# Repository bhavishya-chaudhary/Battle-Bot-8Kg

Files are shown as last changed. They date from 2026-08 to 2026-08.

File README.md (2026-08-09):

# Battle Bot — 8 kg Vertical Spinner

An 8 kg vertical spinner combat robot designed and built by **Team Spartans** for RoboWars. The robot combines a custom aluminium chassis, impact protection, chain-driven weapon system, differential drivetrain, and an ESP32-based control system.

The project was developed through prototype validation, final integration, testing, and competition.

## Specifications

| Parameter | Specification |
|---|---|
| Robot class | 8 kg |
| Configuration | Vertical spinner |
| Drive | Differential / tank steering |
| Drive motors | 24 V geared DC, ~468 RPM |
| Motor drivers | BTS7960 |
| Wheels | 100 mm |
| Weapon motor | D3548 BLDC, 790 KV |
| Weapon ESC | 80 A, 6S |
| Weapon transmission | Chain and sprocket |
| Controller | ESP32-WROOM |
| Radio | FlySky FS-i6S + FS-i10AB |
| Battery | 2 × 3S 4200 mAh 35C LiPo, series |
| Chassis | Aluminium |
| Side protection | 15 mm UHMWPE + stainless steel |
| Low-voltage supply | XL4051 5 A buck converter |
| Control | RC + ESP32 Web UI |
| Firmware | Custom ESP32 firmware with OTA |

## System Architecture

```mermaid
flowchart LR
    TX["FlySky FS-i6S<br/>Transmitter"]
    RX["FS-i10AB<br/>Receiver"]
    ESP["ESP32-WROOM<br/>Control & Safety"]

    DRIVE["BTS7960<br/>Motor Drivers"]
    DM["24 V<br/>Drive Motors"]

    ESC["80 A ESC"]
    WM["D3548<br/>790 KV BLDC"]

    TX --> RX --> ESP
    ESP --> DRIVE --> DM
    ESP --> ESC --> WM
```

The ESP32 acts as the control layer between the RC receiver and the actuators, providing signal processing, mixing, control shaping, weapon control, arming, failsafes, configuration, and diagnostics.

## Mechanical Design

The chassis was designed in **SolidWorks** and packaged around the drivetrain, weapon, battery, and electronics.

The final structure uses:

- Aluminium chassis plates
- 15 mm UHMWPE side protection
- Stainless-steel reinforcement
- Integrated mounts for the drivetrain and weapon
- 100 mm heavy-duty wheels

The weapon uses a vertical spinner driven by a **D3548 790 KV BLDC motor** through a chain and sprocket transmission.

The spinner CAD model has a calculated mass of **557.24 g**. This value refers to the spinner model itself and does not include the complete rotating assembly such as the shaft, sprocket, or motor.

## Drivetrain

The robot uses differential steering with independently controlled left and right drive systems.

Each side uses a 24 V geared DC motor rated at approximately:

- **468 RPM**
- **72.6 N·cm torque**

BTS7960 drivers control the drive motors.

The 100 mm drive wheels were fitted with cut cricket-bat grip rubber to improve traction.

## Control System

The ESP32 acts as the control layer between the RC receiver and the actuators.

The firmware handles:

- RC signal processing
- Differential/tank mixing
- Polynomial throttle and steering curves
- Weapon control
- Independent drive and weapon arming
- Radio-loss failsafe
- Watchdog and reset handling
- Web-based configuration and diagnostics
- OTA firmware updates

### Weapon Control

Weapon output can be selected through three transmitter modes:

| Mode | Output |
|---|---:|
| Controlled | ~50% |
| Higher Power | ~90% |
| Full Power | 100% |

The weapon potentiometer provides the normal control input, while the transmitter switch changes its available output range.

## Safety

The robot uses multiple independent safety mechanisms:

- Physical kill switch
- Radio-loss failsafe
- ESP32 watchdog
- Brownout/reset handling
- Emergency/failsafe command
- Independent drivetrain and weapon arming

The drivetrain and weapon can therefore be armed independently during testing and operation.

## Power & Electronics

The main power system uses **two 3S 4200 mAh 35C LiPo batteries in series**, providing a 6S supply:

- Nominal voltage: **22.2 V**
- Fully charged voltage: **25.2 V**
- Capacity: **4200 mAh**

The electrical system includes an 80 A weapon ESC, BTS7960 motor drivers, XL4051 buck converter, TVS protection, AWG 10 high-current wiring, XT60 connectors, and a 24 V cooling fan.

## Development

The robot was developed in stages rather than integrating the final combat system immediately.

```mermaid
flowchart LR
    A["CAD &<br/>System Design"]
    B["Simplified<br/>Prototype"]
    C["Electronics &<br/>Firmware Validation"]
    D["Final<br/>Integration"]
    E["RoboWars"]

    A --> B --> C --> D --> E
```

The prototype was used to validate the ESP32 control system, RC communication, motor control, weapon control, mixing, and safety logic before the final chassis was fabricated.

The prototype used a direct flexible weapon coupling, while the final robot used the chain-and-sprocket transmission.

## Competition & Failure

The completed robot competed at **RoboWars** and reached Round 2.

During combat, the **weapon transmission sprocket broke under loading**, stopping the weapon and contributing to the loss.

The failure exposed a limitation that was not apparent during normal testing: combat introduces transient shock loads significantly different from steady-state operation. It highlighted the need to consider impact loading and transmission component strength when designing combat mechanisms.

## My Contribution

This was a team project under **Team Spartans**. My work covered the mechanical design, electronics integration, embedded control, and system integration.

### Mechanical

- Designed the main chassis in SolidWorks
- Worked on internal packaging and component placement
- Designed the weapon mounting/support structure
- Worked on drivetrain and weapon transmission design

### Electronics & Control

- Designed and integrated the electronics architecture
- Developed the ESP32 control system
- Implemented mixing and polynomial control curves
- Implemented weapon control and power modes
- Implemented arming and failsafe logic
- Developed the Web UI and OTA functionality

### Integration

- Validated the prototype
- Integrated mechanical, electrical, and software systems
- Worked on final assembly and testing

## Project Status

**Completed — Competed at RoboWars**

The robot reached competition, with the weapon transmission sprocket failing during Round 2.

## License

This project is released under the [MIT License](LICENSE).

---

## Images

Unless otherwise stated, all photographs, renders, and project images in this repository are © Bhavishya Chaudhary.

The images are provided to document the development of the project and may not be reproduced, redistributed, or used in other projects without permission.

The source code in this repository remains licensed under the MIT License.

---

## Author

**Bhavishya Chaudhary**

If you have any questions or suggestions, feel free to connect with me on LinkedIn or GitHub.

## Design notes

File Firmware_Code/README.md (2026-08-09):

This directory contains CAD model related to this project.

Copyrights and Usage Restrictions:
Unless otherwise stated, all CAD models in this repository are © Bhavishya Chaudhary.

The CAD are provided to document the development of the project and may not be reproduced, redistributed, or used in other projects without permission, for permission you can contact me on LinkedIn www.linkedin.com/in/bhavishya-chaudhary-svnit .

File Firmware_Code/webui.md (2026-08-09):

# Web UI

## Access

-   **Wi-Fi SSID:** `update it in firmware before flashing it at line 45`
-   **Wi-Fi Password:** `update it in firmware before flashing it at line 46`
-   **Dashboard:** `http://<ESP32-IP>/`
-   **OTA Update:** `http://<ESP32-IP>/update`
-   **OTA Username:** `admin`
-   **OTA Password:** `ota_secret_99`
-   **Telnet:** `<ESP32-IP>:23`

## Dashboard

### Live Telemetry

-   14-channel iBUS monitor
-   Throttle raw / output
-   Steering raw / output
-   Left / right motor speed
-   Left / right forward / reverse PWM
-   Arm status
-   ESC status
-   Weapon lock status
-   Weapon limit
-   Target / current weapon PWM
-   Weapon output percentage
-   Ramping status
-   Failsafe status
-   RC signal age
-   Good / bad iBUS frames
-   Uptime
-   Wi-Fi RSSI
-   Free heap
-   ESP32 IP address
-   System status

### Drive Tuning

-   Left Forward trim
-   Left Reverse trim
-   Right Forward trim
-   Right Reverse trim
-   Maximum throttle
-   Maximum steering
-   Throttle curve
-   Steering curve
-   Throttle deadzone
-   Steering deadzone
-   Save All
-   Reset All
-   EEPROM persistence

### Serial Monitor

-   Live firmware log
-   Clear log

## OTA Update

-   Authenticated firmware upload
-   `.bin` firmware update
-   Automatic reboot after successful update

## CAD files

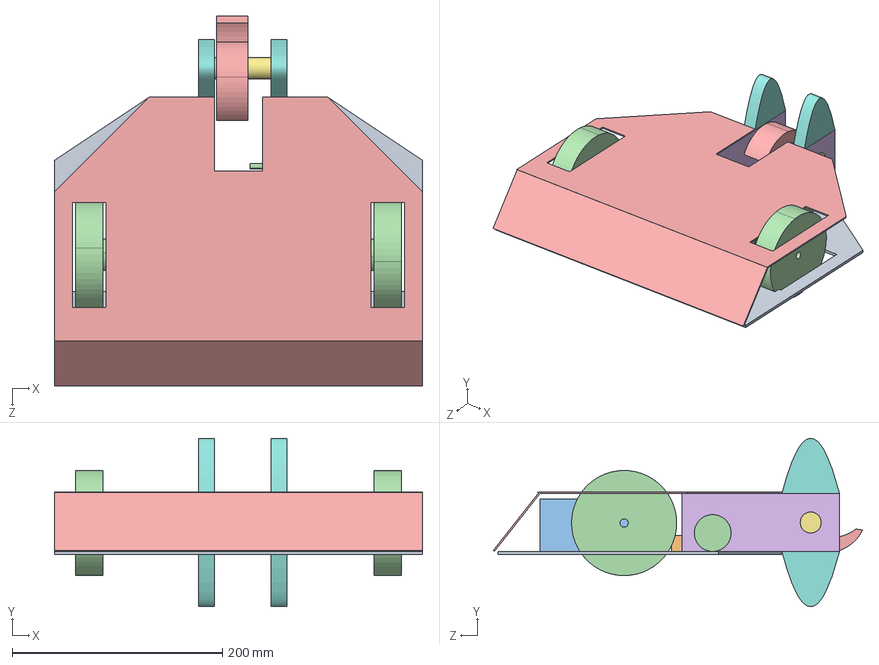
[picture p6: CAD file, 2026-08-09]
CAD/Main_Bot.STEP
350.0 x 160.0 x 351.5 mm
Base_plate
L_clamp x 2
Motor x 2
Wheel x 2
Top_Plate
Bearing_housing x 2
Shaft
Front_support x 4
Battery x 2
ESC
Motor_Driver x 2
BLDC_motor
Attacker_v5

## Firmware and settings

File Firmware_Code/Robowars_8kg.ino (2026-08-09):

/*
 * ================================================================
 *  BATTLE BOT CONTROLLER v7.2
 *  ESP32 WROOM -- NO EXTERNAL LIBRARIES FOR IBUS
 * ================================================================
 *
 *  v7.2 CHANGES:
 *    - ESC arm is hardware arming sequence only (3s 1000us at boot)
 *    - "Armed" on dashboard = CH5 arm lock (drive + weapon gate)
 *    - CH7 (3-pos) is weapon lock/limit:
 *        Pos1 = LOCKED (weapon always 1000us, no spin)
 *        Pos2 = UNLOCKED, limit 3/6 (50%)
 *        Pos3 = UNLOCKED, limit 5/6 (83%)
 *    - CH8 override still goes to 100% (bypasses limit, not lock)
 *    - CH8 override ONLY works when CH7 is Pos2 or Pos3 (unlocked)
 *    - ESC Armed display now shows ESC hardware arm status only
 *    - Weapon Lock display shows CH7 lock state
 *    - Poll 100ms, PollLog 250ms
 *
 *  WEAPON LOGIC:
 *    CH5 OFF  -> all stopped (drive + weapon)
 *    CH5 ON + CH7 Pos1 -> drive works, weapon LOCKED at 1000us
 *    CH5 ON + CH7 Pos2 -> drive + weapon at knob * 50%
 *    CH5 ON + CH7 Pos3 -> drive + weapon at knob * 83%
 *    CH5 ON + CH7 Pos2/3 + CH8 ON -> weapon 100% override
 *
 *  EEPROM LAYOUT (v7.1 compatible):
 *    Byte 0:     Magic (0xBC)
 *    Byte 1-16:  4x float trims
 *    Byte 17-32: maxT, maxS, curveT, curveS, deadT, deadS
 *
 * ================================================================
 */

#include <WiFi.h>
#include <WebServer.h>
#include <Update.h>
#include <EEPROM.h>
#include <esp_task_wdt.h>

// ================================================================
//  WIFI CREDENTIALS -- EDIT THESE
// ================================================================

const char* WIFI_SSID     = "enter your Wifi name here";
const char* WIFI_PASSWORD = "enter your Wifi password here";

// ================================================================
//  DEBUG
// ================================================================

#define DEBUG_MODE false
#define RAMP_TRACE true

// ================================================================
//  WEB OTA SETTINGS
// ================================================================

const char* OTA_USERNAME  = "admin";
const char* OTA_PASSWORD  = "ota_secret_99";

// ================================================================
//  WIFI SETTINGS
// ================================================================

const unsigned long WIFI_CONNECT_TIMEOUT_MS = 10000;
const unsigned long WIFI_ACTIVE_TIMEOUT_MS  = 120000;

#define TELNET_PORT 23

// ================================================================
//  PINS
// ================================================================

#define IBUS_RX_PIN     16

#define LEFT_RPWM_PIN   25
#define LEFT_LPWM_PIN   26
#define RIGHT_RPWM_PIN  27
#define RIGHT_LPWM_PIN  13

#define ESC_PIN         33

// ================================================================
//  LEDC CHANNELS
// ================================================================

#define LEDC_CH_L_FWD   0
#define LEDC_CH_L_REV   1
#define LEDC_CH_R_FWD   2
#define LEDC_CH_R_REV   3
#define LEDC_CH_ESC     4

// ================================================================
//  IBUS
// ================================================================

#define IBUS_CH_STEERING    0
#define IBUS_CH_THROTTLE    1
#define IBUS_CH_ARM         4
#define IBUS_CH_RAMP        5
#define IBUS_CH_LIMIT       6
#define IBUS_CH_OVERRIDE    7
#define IBUS_CH_KNOB        9

#define IBUS_CHANNELS       14
#define IBUS_LENGTH         32
#define IBUS_COMMAND        0x40

// ================================================================
//  PWM
// ================================================================

#define DRIVE_PWM_FREQ       20000
#define DRIVE_PWM_RES        8
#define ESC_PWM_FREQ         50
#define ESC_PWM_RES          16

// ================================================================
//  TIMING
// ================================================================

#define FAILSAFE_TIMEOUT_MS  250
#define ESC_ARM_TIME_MS      3000

#define RAMP_SLOW_STEP       10
#define RAMP_MEDIUM_STEP     25
#define RAMP_INTERVAL_MS     10

#define DEBUG_INTERVAL_MS    500

// ================================================================
//  EEPROM v7.1
// ================================================================

#define EEPROM_SIZE          36
#define EEPROM_MAGIC_V71     0xBC
#define EEPROM_ADDR_MAGIC    0
#define EEPROM_ADDR_LF       1
#define EEPROM_ADDR_LR       5
#define EEPROM_ADDR_RF       9
#define EEPROM_ADDR_RR       13
#define EEPROM_ADDR_MAXT     17
#define EEPROM_ADDR_MAXS     19
#define EEPROM_ADDR_CURVT    21
#define EEPROM_ADDR_CURVS    25
#define EEPROM_ADDR_DEADT    29
#define EEPROM_ADDR_DEADS    31

// ================================================================
//  WATCHDOG
// ================================================================

#define WDT_TIMEOUT_SEC  2

// ================================================================
//  SERIAL LOG RING BUFFER
// ================================================================

#define LOG_BUF_SIZE 4096

char logRing[LOG_BUF_SIZE];
volatile int logHead = 0;
volatile int logCount = 0;

void logWrite(const char* s) {
    int len = strlen(s);
    for (int i = 0; i < len; i++) {
        logRing[logHead] = s[i];
        logHead = (logHead + 1) % LOG_BUF_SIZE;
        if (logCount < LOG_BUF_SIZE) logCount++;
    }
}

void logWriteLn(const char* s) {
    logWrite(s);
    logWrite("\n");
}

// ================================================================
//  OBJECTS
// ================================================================

WebServer webServer(80);
WiFiServer telnetServer(TELNET_PORT);
WiFiClient telnetClient;
bool telnetConnected    = false;
bool telnetFirstDraw    = true;

// ================================================================
//  IBUS STATE
// ================================================================

uint8_t ibusBuffer[IBUS_LENGTH];
uint8_t ibusIndex = 0;
uint16_t channels[IBUS_CHANNELS];
bool ibusFrameReady = false;
unsigned long lastIbusFrame = 0;

// ================================================================
//  GLOBALS
// ================================================================

bool wifiActive       = false;
bool wifiShutdown     = false;
bool otaInProgress    = false;
bool escArmed         = false;   // Hardware ESC arm (3s sequence)

bool armLockReleased  = false;   // CH5 software arm (drive + weapon gate)
bool armSeenOff       = false;

bool weaponLocked     = true;    // CH7 Pos1 = locked

int currentWeaponPWM  = 1000;
int targetWeaponPWM   = 1000;
int prevWeaponPWM     = 1000;

unsigned long bootTime            = 0;
unsigned long wifiStartTime       = 0;
unsigned long lastValidSignalTime = 0;
unsigned long lastDebugTime       = 0;
unsigned long lastRampTime        = 0;

unsigned long goodFrames = 0;
unsigned long badFrames  = 0;

int debugLeftSpd      = 0;
int debugRightSpd     = 0;

uint32_t debugLeftFwd  = 0;
uint32_t debugLeftRev  = 0;
uint32_t debugRightFwd = 0;
uint32_t debugRightRev = 0;

int debugThrotRaw = 0;
int debugSteerRaw = 0;
int debugThrotOut = 0;
int debugSteerOut = 0;

bool wasRamping        = false;
int  rampStartPWM      = 1000;
int  lastRampPrint     = 1000;

char statusLine[80] = "";

bool inFailsafe = false;
bool debugActive = false;
int weaponLimitPos = 1;

IPAddress assignedIP;

// TUNING VALUES (EEPROM)
float trimLF = 1.00f;
float trimLR = 1.00f;
float trimRF = 1.00f;
float trimRR = 1.00f;

int16_t maxThrottle = 255;
int16_t maxSteering = 150;

float curveThrottle = 2.0f;
float curveSteering = 2.0f;

int16_t deadThrottle = 15;
int16_t deadSteering = 15;

// Print buffers
char usbBuf[1400];
int  usbPos = 0;

char telBuf[1600];
int  telPos = 0;

// ================================================================
//  FUNCTION DECLARATIONS
// ================================================================

void setupMotorPWM();
void setupWiFiAndWeb();
void setupIBUS();
void setupWatchdog();
void setupEEPROM();
void handleWiFi();
void handleTelnet();
void updateDebugState();
void readIBUS();
bool isSignalValid();
void processArmLock();
void processDrive();
void processWeapon();
int  applyCurve(int input, int maxOutput, float exponent, int deadzone);
void setMotor(int speed, uint8_t fwdCh, uint8_t revCh, float tFwd, float tRev);
void setESC(int pulseUs);
void stopAll();
void stopDrive();
void printDashboard();
void setStatus(const char* msg);
void saveSettingsToEEPROM();
void loadSettingsFromEEPROM();
void setupWebRoutes();

void usbPrint(const char* s);
void usbLine(const char* s);
void telPrint(const char* s);
void telLine(const char* s);

// ================================================================
//  BUFFER HELPERS
// ================================================================

void setStatus(const char* msg) {
    strncpy(statusLine, msg, sizeof(statusLine) - 1);
    statusLine[sizeof(statusLine) - 1] = '\0';
    logWriteLn(msg);
}

void usbPrint(const char* s) {
    int len = strlen(s);
    if (usbPos + len < (int)sizeof(usbBuf) - 1) {
        memcpy(usbBuf + usbPos, s, len);
        usbPos += len;
    }
}

void usbLine(const char* s) {
    usbPrint(s);
    usbPrint("\r\n");
}

void telPrint(const char* s) {
    int len = strlen(s);
    if (telPos + len < (int)sizeof(telBuf) - 1) {
        memcpy(telBuf + telPos, s, len);
        telPos += len;
    }
}

void telLine(const char* s) {
    telPrint(s);
    telPrint("\r\n");
}

// ================================================================
//  CONFIGURABLE CURVE FUNCTION
// ================================================================

int applyCurve(int input, int maxOutput, float exponent, int deadzone) {
    if (input == 0) return 0;

    int sign = (input > 0) ? 1 : -1;
    int absIn = abs(input);

    if (absIn <= deadzone) return 0;

    float normalized = (float)(absIn - deadzone) / (float)(255 - deadzone);

    if (normalized > 1.0f) normalized = 1.0f;
    if (normalized < 0.0f) normalized = 0.0f;

    float curved = powf(normalized, exponent);

    int result = (int)(curved * (float)maxOutput + 0.5f);

    if (result < 1 && absIn > deadzone) result = 1;
    if (result > maxOutput) result = maxOutput;

    return result * sign;
}

// ================================================================
//  DEBUG STATE
// ================================================================

void updateDebugState() {
    if (DEBUG_MODE) {
        debugActive = true;
    } else if (wifiActive) {
        debugActive = true;
    } else {
        debugActive = false;
    }
}

// ================================================================
//  EEPROM
// ================================================================

void setupEEPROM() {
    EEPROM.begin(EEPROM_SIZE);
    loadSettingsFromEEPROM();
}

void loadSettingsFromEEPROM() {
    uint8_t magic = EEPROM.read(EEPROM_ADDR_MAGIC);

    if (magic == EEPROM_MAGIC_V71) {
        EEPROM.get(EEPROM_ADDR_LF, trimLF);
        EEPROM.get(EEPROM_ADDR_LR, trimLR);
        EEPROM.get(EEPROM_ADDR_RF, trimRF);
        EEPROM.get(EEPROM_ADDR_RR, trimRR);
        EEPROM.get(EEPROM_ADDR_MAXT, maxThrottle);
        EEPROM.get(EEPROM_ADDR_MAXS, maxSteering);
        EEPROM.get(EEPROM_ADDR_CURVT, curveThrottle);
        EEPROM.get(EEPROM_ADDR_CURVS, curveSteering);
        EEPROM.get(EEPROM_ADDR_DEADT, deadThrottle);
        EEPROM.get(EEPROM_ADDR_DEADS, deadSteering);

        if (trimLF < 0.0f || trimLF > 1.0f || isnan(trimLF)) trimLF = 1.0f;
        if (trimLR < 0.0f || trimLR > 1.0f || isnan(trimLR)) trimLR = 1.0f;
        if (trimRF < 0.0f || trimRF > 1.0f || isnan(trimRF)) trimRF = 1.0f;
        if (trimRR < 0.0f || trimRR > 1.0f || isnan(trimRR)) trimRR = 1.0f;

        if (maxThrottle < 10 || maxThrottle > 255) maxThrottle = 255;
        if (maxSteering < 10 || maxSteering > 255) maxSteering = 150;

        if (curveThrottle < 1.0f || curveThrottle > 3.0f || isnan(curveThrottle)) curveThrottle = 2.0f;
        if (curveSteering < 1.0f || curveSteering > 3.0f || isnan(curveSteering)) curveSteering = 2.0f;

        if (deadThrottle < 0 || deadThrottle > 50) deadThrottle = 15;
        if (deadSteering < 0 || deadSteering > 50) deadSteering = 15;

        Serial.println("[EEPROM] Loaded settings v7.1:");
    } else {
        trimLF = 1.0f; trimLR = 1.0f; trimRF = 1.0f; trimRR = 1.0f;
        maxThrottle = 255; maxSteering = 150;
        curveThrottle = 2.0f; curveSteering = 2.0f;
        deadThrottle = 15; deadSteering = 15;
        Serial.println("[EEPROM] No v7.1 data -- using defaults:");
    }

    char msg[120];
    sprintf(msg, "[SET] Trim: LF=%.2f LR=%.2f RF=%.2f RR=%.2f",
            trimLF, trimLR, trimRF, trimRR);
    Serial.println(msg);
    logWriteLn(msg);

    sprintf(msg, "[SET] MaxT=%d MaxS=%d CurveT=%.1f CurveS=%.1f DeadT=%d DeadS=%d",
            maxThrottle, maxSteering, curveThrottle, curveSteering,
            deadThrottle, deadSteering);
    Serial.println(msg);
    logWriteLn(msg);
}
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
void loop() {

    esp_task_wdt_reset();

    if (!wifiShutdown) {
        handleWiFi();
        handleTelnet();
    }

    updateDebugState();

    if (otaInProgress) {
        stopAll();
        esp_task_wdt_reset();
        if (wifiActive) webServer.handleClient();
        delay(1);
        return;
    }

    readIBUS();

    bool signalOK = isSignalValid();
    if (signalOK) {
        lastValidSignalTime = millis();
    }

    unsigned long signalAge = millis() - lastValidSignalTime;

    // FAILSAFE
    if (signalAge > FAILSAFE_TIMEOUT_MS) {
        stopAll();
        armLockReleased = false;
        armSeenOff = false;
        weaponLocked = true;

        if (!inFailsafe) {
            inFailsafe = true;
            setStatus("** FAILSAFE ** NO SIGNAL");
        }

        if (debugActive) printDashboard();
        return;
    }

    if (inFailsafe) {
        inFailsafe = false;
        setStatus("Signal recovered -- flip CH5 to arm");
    }

    // ESC HARDWARE ARM (3s 1000us at boot)
    if (!escArmed) {
        if (millis() - bootTime >= ESC_ARM_TIME_MS) {
            escArmed = true;
            setStatus("ESC init done -- system ready");
        } else {
            unsigned long rem = ESC_ARM_TIME_MS - (millis() - bootTime);
            sprintf(statusLine, "ESC init... %lu.%lus",
                    rem / 1000, (rem % 1000) / 100);
            processArmLock();
            stopDrive();
            setESC(1000);
            currentWeaponPWM = 1000;
            if (debugActive) printDashboard();
            return;
        }
    }

    processArmLock();
    processDrive();
    processWeapon();

    if (debugActive) printDashboard();
}

// ================================================================
//  WIFI HANDLER -- 2 MIN TIMEOUT
// ================================================================

void handleWiFi() {
    if (!wifiActive) return;

    webServer.handleClient();

    if (otaInProgress) return;

    if (telnetConnected && telnetClient.connected()) {
        wifiStartTime = millis();
        return;
    }

    if (millis() - wifiStartTime > WIFI_ACTIVE_TIMEOUT_MS) {
        Serial.println("[WIFI] 2-min timeout -- shutting down");
        logWriteLn("WiFi timeout -- shutting down");

        if (telnetConnected) {
            telnetClient.stop();
            telnetConnected = false;
        }
        telnetServer.stop();
        webServer.stop();
        WiFi.disconnect(true);
        delay(100);
        WiFi.mode(WIFI_OFF);
        delay(100);

        wifiActive = false;
        wifiShutdown = true;

        if (DEBUG_MODE) {
            setStatus("WiFi OFF -- USB debug stays (DEBUG_MODE)");
        } else {
            setStatus("WiFi OFF -- max performance");
        }
    }
}

// ================================================================
//  ARM LOCK (CH5 = master arm for drive + weapon)
// ================================================================

void processArmLock() {
    uint16_t armVal = channels[IBUS_CH_ARM];

    if (armVal < 1500) {
        armSeenOff = true;
        if (armLockReleased) {
            armLockReleased = false;
            currentWeaponPWM = 1000;
            targetWeaponPWM = 1000;
            setESC(1000);
            stopDrive();
            setStatus("DISARMED -- all stopped");
        }
    } else {
        if (armSeenOff && !armLockReleased) {
            armLockReleased = true;
            setStatus("*** ARMED *** DRIVE + WEAPON GATE OPEN");
        }
    }
}

// ================================================================
//  DRIVE
// ================================================================

void processDrive() {
    if (!armLockReleased) {
        stopDrive();
        debugThrotRaw = 0;
        debugSteerRaw = 0;
        debugThrotOut = 0;
        debugSteerOut = 0;
        return;
    }

    int throttleRaw = map(channels[IBUS_CH_THROTTLE], 1000, 2000, -255, 255);
    int steeringRaw = map(channels[IBUS_CH_STEERING], 1000, 2000, -255, 255);

    int throttle = applyCurve(throttleRaw, maxThrottle, curveThrottle, deadThrottle);
    int steering = applyCurve(steeringRaw, maxSteering, curveSteering, deadSteering);

    debugThrotRaw = throttleRaw;
    debugSteerRaw = steeringRaw;
    debugThrotOut = throttle;
    debugSteerOut = steering;

    int leftSpd  = constrain(throttle + steering, -255, 255);
    int rightSpd = constrain(throttle - steering, -255, 255);

    debugLeftSpd  = leftSpd;
    debugRightSpd = rightSpd;

    setMotor(leftSpd,  LEDC_CH_L_FWD, LEDC_CH_L_REV, trimLF, trimLR);
    setMotor(rightSpd, LEDC_CH_R_FWD, LEDC_CH_R_REV, trimRF, trimRR);
}

// ================================================================
//  WEAPON
//
//  CH7 (3-pos limit switch):
//    Pos1 (<1300) = LOCKED  -> weapon always 1000us
//    Pos2 (1300-1700) = UNLOCKED, limit 3/6 (50%)
//    Pos3 (>1700) = UNLOCKED, limit 5/6 (83%)
//
//  CH8 override: only works when CH7 is Pos2 or Pos3
//  CH5 must be armed for any weapon output
// ================================================================

void processWeapon() {

    // Read CH7 limit/lock switch
    uint16_t limRaw = channels[IBUS_CH_LIMIT];
    if (limRaw < 1300) {
        weaponLimitPos = 1;
        weaponLocked = true;
    } else if (limRaw < 1700) {
        weaponLimitPos = 2;
        weaponLocked = false;
    } else {
        weaponLimitPos = 3;
        weaponLocked = false;
    }

    // Determine target
    targetWeaponPWM = 1000;

    if (!armLockReleased) {
        // CH5 not armed -- everything off
        targetWeaponPWM = 1000;
    }
    else if (weaponLocked) {
        // CH7 Pos1 -- weapon locked, force 1000us
        targetWeaponPWM = 1000;
    }
    else if (channels[IBUS_CH_OVERRIDE] > 1500) {
        // CH8 override -- 100% (only reaches here if CH7 unlocked)
        targetWeaponPWM = 2000;
    }
    else {
        // Normal operation: knob * limit factor
        float limitFactor;
        if (weaponLimitPos == 2) limitFactor = 3.0f / 6.0f;
        else                     limitFactor = 5.0f / 6.0f;

        int knobRaw = constrain((int)channels[IBUS_CH_KNOB], 1000, 2000);
        float knobFrac = (float)(knobRaw - 1000) / 1000.0f;

        targetWeaponPWM = 1000 + (int)(knobFrac * limitFactor * 1000.0f);
        targetWeaponPWM = constrain(targetWeaponPWM, 1000, 2000);
    }

    // Ramp logic
    prevWeaponPWM = currentWeaponPWM;

    if (targetWeaponPWM <= 1000) {
        // Instant stop -- no ramp down delay for safety
        currentWeaponPWM = 1000;
    }
    else {
        if (millis() - lastRampTime >= RAMP_INTERVAL_MS) {
            lastRampTime = millis();

            uint16_t rampRaw = channels[IBUS_CH_RAMP];
            int rampStep;
            if (rampRaw < 1300)      rampStep = RAMP_SLOW_STEP;
            else if (rampRaw < 1700) rampStep = RAMP_MEDIUM_STEP;
            else                     rampStep = 0;

            if (rampStep == 0) {
                currentWeaponPWM = targetWeaponPWM;
            } else {
                if (currentWeaponPWM < targetWeaponPWM) {
                    currentWeaponPWM += rampStep;
                    if (currentWeaponPWM > targetWeaponPWM)
                        currentWeaponPWM = targetWeaponPWM;
                }
                else if (currentWeaponPWM > targetWeaponPWM) {
                    int downStep = rampStep * 3;
                    if (downStep < 30) downStep = 30;
                    currentWeaponPWM -= downStep;
                    if (currentWeaponPWM < targetWeaponPWM)
                        currentWeaponPWM = targetWeaponPWM;
                }
            }
        }
    }

    currentWeaponPWM = constrain(currentWeaponPWM, 1000, 2000);
    setESC(currentWeaponPWM);

    // Ramp trace
    if (RAMP_TRACE && debugActive) {
        bool isRamping = (currentWeaponPWM != targetWeaponPWM);

        if (isRamping && !wasRamping) {
            rampStartPWM = prevWeaponPWM;
            lastRampPrint = prevWeaponPWM;
            char msg[60];
            sprintf(msg, "RAMP: %d -> %d", prevWeaponPWM, targetWeaponPWM);
            setStatus(msg);
            wasRamping = true;
        }

        if (isRamping && wasRamping) {
            if (abs(currentWeaponPWM - lastRampPrint) >= 100) {
                lastRampPrint = currentWeaponPWM;
                char msg[40];
                sprintf(msg, "RAMPING: %dus (%d%%)",
                        currentWeaponPWM, (currentWeaponPWM - 1000) / 10);
                setStatus(msg);
            }
        }
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
